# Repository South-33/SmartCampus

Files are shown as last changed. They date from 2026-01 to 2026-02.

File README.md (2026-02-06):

# Smart Classroom System

A two-node wireless system for secure gate access and intelligent energy management.

---

## System Overview

| Node | Role | Components |
|---|---|---|
| **Node A (Gatekeeper)** | Door access control | ESP32 + PN532 NFC + Finger Vein + Relay |
| **Node B (Watchman)** | Occupancy monitoring & power control | ESP32 + HLK-LD2410C Radar + Relay |
| **Communication** | ESP-NOW (direct ESP-to-ESP) | ~50m indoor range |

---

## Tech Stack

| Layer | Technology | Why |
|---|---|-----|
| **Mobile App** | React Native + Expo | Cross-platform, TypeScript, EAS cloud builds |
| **Backend** | Convex | Real-time, TypeScript, scheduled functions |
| **Firmware** | Arduino/PlatformIO | ESP32 HTTP client to Convex |

### Mobile App Libraries

| Feature | Library |
|---|---|
| NFC | `react-native-nfc-manager` |
| Biometrics (FaceID) | `expo-local-authentication` |
| GPS | `expo-location` |
| Push Notifications | `expo-notifications` |

### Expo Go Limits (Testing)

- Face ID is not available in Expo Go (it falls back to passcode)
- NFC is not available in Expo Go (requires a dev client build)
- Android dev build steps: `mobile/ANDROID_DEV_BUILD.md`

### Architecture

```
┌─────────────────────────────────────────┐
│           MOBILE APP                    │
│   React Native + Expo                   │
└────────────────┬────────────────────────┘
                 │ TypeScript
                 ▼
┌─────────────────────────────────────────┐
│            BACKEND                      │
│   Convex (real-time + scheduled jobs)   │
└────────────────┬────────────────────────┘
                 │ HTTP
                 ▼
┌─────────────────────────────────────────┐
│           HARDWARE                      │
│   ESP32 + PN532 (local whitelist)       │
└─────────────────────────────────────────┘
```

## Hardware Inventory

| Component | Qty | Function | Placement |
|---|-----|---|---|
| ESP32 WROOM-32 | 2 | Microcontrollers | Door frame / Ceiling |
| PN532 NFC Module | 2 | Reader/Tag Emulation | Outside door (1 spare) |
| HLK-LD2410C | 1 | mmWave Presence Sensor | Ceiling (facing room) |
| 5V Relay Module | 2 | Lock control / Power switch | Door frame / Electrical box |
| Waveshare Finger Vein | 1 | Biometric authentication | Door frame (beside NFC) |
| HLK-TX510 Face Recognition | 1 | Secondary biometric | Door frame |
| NTAG215 Cards | 10 | Physical student keys | Student possession |

---

## Wiring Diagrams

### Node A: Gatekeeper (Door) - UPDATED (SAFE)

| Component | Pin | ESP32 Pin | Notes |
|---|-----|---|---|
| **PN532 NFC** | VCC | **VIN (5V)** | Has onboard 3.3V regulator |
| | GND | GND | |
| | SDA | GPIO 21 | Direct connect OK (3.3V I2C) |
| | SCL | GPIO 22 | Direct connect OK (3.3V I2C) |
| **Relay #1** | IN | **GPIO 25** | *Safe pin (not GPIO 4)* |
| **Finger Vein** | VCC | **3V3** | Module requires 3.3V |
| | GND | GND | |
| | TX | GPIO 16 | Direct connect OK (3.3V UART) |
| | RX | GPIO 17 | Direct connect OK (3.3V UART) |
| **TX510 Face** | VCC | **5V Rail** | Module Max 500mA (Supply >800mA rec.) |
| | GND | GND | |
| | TX | GPIO 4 | Direct connect OK (3.3V UART1) |
| | RX | GPIO 5 | Direct connect OK (3.3V UART1) |

> **Note on Level Shifters:**
> - **PN532**: NOT required - uses 3.3V I2C logic despite 5V VCC input
> - **Finger Vein**: NOT required - native 3.3V module
> - **TX510**: NOT required - confirmed 3.3V UART domain (Pins 38/39)
> - Add **4.7K pull-up resistors** on I2C lines (SDA/SCL) for reliable PN532 communication

### Node B: Watchman (Ceiling) - UPDATED (SAFE)

| Component | Pin | ESP32 Pin | Notes |
|---|-----|---|---|
| **HLK-LD2410** | VCC | **VIN (5V)** | MUST be 5V. 3.3V will not work. |
| | GND | GND | |
| | TX | GPIO 16 | Direct connect OK |
| | RX | GPIO 17 | Direct connect OK |
| **Relay #2** | IN | **GPIO 26** | *Moved from GPIO 5 (Boot risk)* |

> ⚠️ **Critical:** Node B must be powered by a separate always-on circuit. If Relay #2 controls its own power, opening it kills the ESP32.

---

## User Flows

### Flow 1: Card Onboarding

Student links their physical NFC card to their account (one-time setup).

```mermaid
flowchart TD
    A[🎓 Student receives card] --> B[Opens app]
    B --> C[Taps 'Link Card']
    C --> D[📱 Phone reads card UID]
    D --> E{Success?}
    E -->|Yes| F[Send to server]
    E -->|No| G[❌ Retry]
    F --> H[✅ Card linked!]
```

---

### Flow 2: Physical Card Access

Student taps card. **ALWAYS uses local whitelist (instant, no server call).**

```mermaid
flowchart TD
    A[🎓 Tap card] --> B[PN532 reads UID]
    B --> C[Check LOCAL whitelist]
    C --> D{In list?}
    
    D -->|Yes| E[🔓 Door opens]
    D -->|No| F[❌ Denied]
    
    E --> G[Queue access log]
    G --> H{WiFi?}
    H -->|Yes| I[Sync log now]
    H -->|No| J[Sync later]
```

> 💡 **No server call during tap.** Whitelist is pre-synced from server.

---

### Flow 3: Phone Access (Open Gate Only)

No biometric needed. **ALWAYS uses local whitelist.**

```mermaid
flowchart TD
    A[🎓 Open app] --> B[Tap 'Open Gate']
    B --> C[📱 NFC Writer mode]
    C --> D[60 second timer]
    D --> E[Tap phone to reader]
    E --> F[Phone writes: studentId]
    F --> G[ESP32 checks LOCAL whitelist]
    G --> H{In list?}
    
    H -->|Yes| I[🔓 Door opens]
    H -->|No| J[❌ Denied]
    
    I --> K[Queue log for sync]
```

**Payload:** `{ studentId, action: "OPEN_GATE" }`

**App Screen States:**

```mermaid
flowchart LR
    A[📱 Timer Screen] -->|Phone detects scan| B[✅ Success Screen]
    A -->|60s expires| C[❌ Timeout Screen]
```

| State | UI | Trigger |
|---|-----|---|
| **Timer** | "⏱️ 47 seconds - Tap phone to reader" | User clicks Open Gate |
| **Success** | "✅ Scanned! Door should open" | NFC write callback fires |
| **Timeout** | "❌ Time expired, try again" | 60 seconds pass |

---

### Flow 4: Attendance (Biometric Required)

Opens door AND records attendance. **Requires FaceID/Fingerprint.**

```mermaid
flowchart TD
    A[🎓 Open app] --> B[Tap 'Attendance']
    B --> C{Has biometric HW?}
    
    C -->|No| D[❌ Not supported]
    C -->|Yes| E{Biometric enrolled?}
    
    E -->|No| F[⚠️ Set up in Settings]
    E -->|Yes| G[Prompt FaceID]
    
    G --> H{Auth OK?}
    H -->|No| I[❌ Failed]
    H -->|Yes| J[📱 NFC Writer mode]
    
    J --> K[Capture: studentId + time + GPS]
    K --> L[60 second timer]
    L --> M[Tap phone to reader]
    M --> N[ESP32 stores with scanOrder]
    
    N --> O{WiFi?}
    O -->|Online| P[POST + serverTime]
    O -->|Offline| Q[Queue in NVS]
    
    P --> R[🔓 Door + ✅ Attendance]
    Q --> S[🔓 Door + 📋 Queued]
```

**Payload:** `{ studentId, deviceTime, gps, action: "ATTENDANCE" }`

**ESP32 adds:** `{ scanOrder, espTime, synced: false }`

---

### Flow 5: Energy Saving

Radar cuts power when room is empty for 15 minutes.

```
STATE MACHINE:

┌──────────────────────────────────────────────────────────────┐
│                                                              │
│   ┌─────────┐    No motion     ┌─────────┐    15 min     ┌─────────┐
│   │OCCUPIED │ ───────────────► │  GRACE  │ ────────────► │ STANDBY │
│   │Power ON │                  │Power ON │               │Power OFF│
│   └─────────┘                  └─────────┘               └─────────┘
│        ▲                            │                         │
│        │                            │ Motion                  │ Motion
│        │                            ▼                         ▼
│        └──────────────────── INSTANT RECOVERY ◄───────────────┘
│                                                              │
└──────────────────────────────────────────────────────────────┘
```

| State | Power | Trigger to next state |
|---|---|---|
| **OCCUPIED** | ON | No motion → GRACE |
| **GRACE** | ON | 15 min no motion → STANDBY |
| **STANDBY** | OFF | Motion detected → OCCUPIED |

---

## Offline Mode

System is **local-first**. No server calls during validation. Server only manages whitelist updates.

### Architecture

**Two-way sync between ESP32 and Server:**

| Direction | What | When |
|---|---|---|
| **Server → ESP32** | Whitelist updates | Periodic (every hour) or on boot |
| **ESP32 → Server** | Access logs + attendance | When WiFi available |

```
┌────────────────────────────────────────────────────────────────┐
│                     SERVER (Convex)                            │
│  • Manage students & rooms                                     │
│  • Push whitelist to each ESP32                                │
│  • Receive logs from ESP32                                     │
└───────────────────────────┬────────────────────────────────────┘
                            │
            ┌───────────────┴───────────────┐
            │         WiFi Sync             │
            │  (not during tap, only sync)  │
            └───────────────┬───────────────┘
                            │
┌───────────────────────────┴────────────────────────────────────┐
│                     ESP32 (Local)                              │
│  • Store room whitelist in NVS                                 │
│  • Validate taps LOCALLY (instant)                             │
│  • Queue logs until WiFi available                             │
└────────────────────────────────────────────────────────────────┘
```

**Key point:** Student taps → validated locally → door opens. No WiFi needed.

### What Happens When

| Event | Action |
|---|---|
| **Student taps** | Check LOCAL whitelist → instant response |
| **WiFi available** | Sync queued logs + check for whitelist updates |
| **Admin adds student** | Server updates whitelist → ESP32 pulls on next sync |
| **WiFi down** | Everything still works, logs queue locally |

### Timestamp Handling

| Mode | Source | Label | Accuracy |
|---|---|---|---|
| Online | Server | `timestampServer` | ✅ Accurate |
| Offline | ESP32 | `timestampLocal` | ⚠️ May drift |

**On reconnect:** Calculate offset, correct queued records.

---

### Anti-Cheat Mechanisms

#### 1. Attendance Time Window

**Single scan only** (no scan OUT = no queue at end of class).

Window: **15 min before class** → **mid-class** (50% of class duration)

```
Class: 09:00 - 10:30 (90 min)

            ATTENDANCE WINDOW
        ◄─────────────────────►
        
08:45   09:00              09:45   10:30
  │       │                  │       │
  ├───────┼──────────────────┤       │
  │15 min │     OPEN         │CLOSED │
  │before │   (can scan)     │       │
```

| Attempt Time | Class 09:00-10:30 | Result |
|---|---|---|
| 08:30 | Too early | ❌ Rejected |
| 08:50 | 10 min before | ✅ Valid |
| 09:15 | During class | ✅ Valid |
| 09:45 | Mid-class cutoff | ✅ Valid (last chance) |
| 10:00 | Past mid-class | ❌ Rejected |

#### 2. Phone Internet Check

Phone includes its internet status in the payload:

```json
{
  "studentId": "stu_123",
  "deviceTime": 1706012345,
  "timeSource": "ntp",      // "ntp" = internet time, "local" = device clock
  "hasInternet": true,
  "gps": { "lat": 13.7, "lng": 100.5 },
  "action": "ATTENDANCE"
}
```

| timeSource | Meaning | Trust Level |
|---|---|---|
| `ntp` | Phone fetched time from internet | ✅ High |
| `local` | Phone used device clock | ⚠️ Low |

#### 3. Suspicious Pattern Detection

Flag students who consistently have "no internet":

```typescript
// Server-side check
function checkSuspiciousPatterns(studentId: string, logs: AttendanceLog[]) {
  const recentLogs = logs.filter(l => l.studentId === studentId && isWithinDays(l, 7));
  const noInternetCount = recentLogs.filter(l => l.timeSource === "local").length;
  const totalCount = recentLogs.length;
  
  // If >50% of attendance has no internet in past week → suspicious
  if (noInternetCount / totalCount > 0.5) {
    alertAdmin({
      type: "SUSPICIOUS_PATTERN",
      studentId,
      message: `${noInternetCount}/${totalCount} scans with no internet this week`
    });
  }
}
```

**Red flags to auto-detect:**
| Pattern | Action |
|---|---|
| >50% "no internet" in 7 days | ⚠️ Flag to admin |
| Attendance outside time window | ❌ Reject |
| GPS > 100m from room | ⚠️ Flag to admin |
| deviceTime vs espTime > 5 min | 🚨 Use espTime only |
| **1 deviceId + 2 accounts in 12h** | 🚨 **Account sharing** |

#### 5. Device Binding (Anti-Sharing)

**Problem:** Student A logs into app, scans attendance, logs out, gives phone to Student B, who logs in and scans.

**Solution:** Include `deviceId` in every payload. Server tracks which devices are used by which accounts.

```json
{
  "studentId": "stu_123",
  "deviceId": "E621E1F8-C36C-495A-93FC-0C247A3E6E5F",
  "deviceTime": 1706012345,
  "action": "ATTENDANCE"
}
```

**Server-side check:**
```typescript
function checkDeviceSharing(deviceId: string, studentId: string) {
  const recentScans = getScansInLast12Hours(deviceId);
  const uniqueAccounts = new Set(recentScans.map(s => s.studentId));
  
  if (uniqueAccounts.size > 1) {
    // 🚨 Same device, multiple accounts = sharing
    alertAdmin({
      type: "DEVICE_SHARING",
      deviceId,
      accounts: [...uniqueAccounts],
      message: `Device used by ${uniqueAccounts.size} accounts in 12h`
    });
  }
}
```

| Scenario | Result |
|---|---|
| 1 device, 1 account | ✅ OK |
| 1 device, 2 accounts in 12h | 🚨 Flag both students |
| 1 device, 2 accounts in 7 days | ⚠️ Maybe new phone, allow |

#### 4. Scan Order (Position)

Students can lie about timestamp. They **cannot** lie about position in line.

| scanOrder | studentId | deviceTime | espTime | Status |
|---|---|---|---|---|
| 1 | stu_007 | 09:01:23 | 09:01:25 | ✅ OK |
| 2 | stu_003 | 09:01:45 | 09:01:30 | ✅ OK |
| 3 | stu_012 | **08:55:00** | 09:01:35 | 🚨 SUS |
| 4 | stu_001 | 09:02:10 | 09:01:40 | ✅ OK |

→ Student #3 claims 08:55 but is position 3. **Use espTime as truth.**

**Scan Order Memory (ESP32 NVS):**

| Data per scan | Size |
|---|---|
| `scanOrder` (uint16) | 2 bytes |
| `studentId` (8 chars) | 8 bytes |
| `espTime` (uint32) | 4 bytes |
| `synced` flag | 1 byte |
| **Total per scan** | **~15 bytes** |

| Scenario | Calculation | Result |
|---|---|---|
| 50 scans/day × 15 bytes | 750 bytes/day | Tiny |
| NVS usable space | ~12-16 KB | Huge margin |
| Days before overflow (no sync) | 16,000 ÷ 750 | **~21 days** |

> 💡 With WiFi syncing every hour, you'll never hit NVS limits. If overflow occurs (rare), oldest records are deleted.

**Flow:**
```
Class starts → scanOrder = 0
Student 1 taps → scanOrder = 1, queued
Student 2 taps → scanOrder = 2, queued
...
WiFi available → Batch upload all → Clear queue
Next class → scanOrder = 0 (reset per class session)
```

---

### Local Whitelist

Each ESP32 stores only students allowed in **its room**:

```json
{
  "whitelistVersion": 42,
  "entries": [
    { "cardUID": "04:A3:2B:...", "studentId": "stu_001" },
    { "cardUID": "04:B7:3C:...", "studentId": "stu_007" }
  ]
}
```

**Sync:** `GET /whitelist?room=101&version=42` → 304 or new list.

---

## Access Control Model

### User Roles

| Role | Door Access | Scan IN | Scan OUT | Biometric | Notes |
|---|---|---|---|---|---|
| **Student** | Enrolled rooms only | ✅ Required | ❌ Not required | IN only | GPS geofencing |
| **Teacher** | All rooms | ✅ Required | ✅ Required | Both IN & OUT | Logs teaching hours |
| **Cleaner/Staff** | All rooms | ❌ Optional | ❌ Optional | None | Access logged only |
| **Admin** | All rooms + dashboard | ❌ Optional | ❌ Optional | None | Can manage everything |

> 💡 **Why no student scan-out?** Students rush to leave class simultaneously. Requiring scan-out creates bottlenecks. Use radar occupancy detection instead if class duration data is needed.

> ⚠️ **Biometric Clarification:** We use on-device authentication (FaceID/Fingerprint). The app receives `true/false` — **no biometric data is collected or transmitted**. Only GPS is collected for geofencing.

**How it works:**
- `role: "student"` → Check `allowedRooms` array
- `role: "teacher" | "cleaner" | "admin"` → Skip room check, allow all

### Database Schema

```typescript
// users (students, teachers, cleaners, admins)
{
  _id: "usr_12345",
  name: "John Doe",
  role: "student" | "teacher" | "cleaner" | "admin",
  status: "enrolled" | "graduated" | "expelled",  // Never delete, just archive
  cardUID: "04:A3:2B:1C:7D:00:00",    // 1 account = 1 card (linking new card overwrites old)
  deviceId: "E621E1F8-C36C...",       // Bound phone for anti-sharing
  allowedRooms: ["room_101", "room_102"]  // Only used if role = "student"
}
```

> 💡 **Archiving Policy:** Users are never deleted. When a student graduates or is expelled, set `status` accordingly. Old attendance records remain for historical reference.

> ⚠️ **1:1 Card Binding:** Each account can only have ONE linked NFC card. If a student links a new card, the old `cardUID` is overwritten. This prevents students from having multiple cards.

```typescript
// rooms
{
  _id: "room_101",
  name: "Computer Lab 101",
  nodeId: "esp32_node_a_001",
  gps: { lat: 13.7563, lng: 100.5018 }
}

// accessLogs
{
  studentId: "stu_12345",
  roomId: "room_101",
  method: "card" | "phone",
  action: "OPEN_GATE" | "ATTENDANCE",
  result: "granted" | "denied",
  timestamp: "2026-01-22T10:30:00Z",
  timestampType: "server" | "local",
  scanOrder?: 5,
  gps?: { lat, lng }
}
```

---

## Security Strategy

| Layer | Implementation |
|---|---|
| **Something you have** | NFC Card / iPhone |
| **Something you are** | FaceID (attendance only) |
| **Somewhere you are** | GPS verification |
| **Replay protection** | scanOrder + nonce |
| **Offline security** | Local whitelist, no signing keys |

### Threat Mitigations

| Threat | Mitigation |
|---|---|
| Fake studentId | Check whitelist |
| Fake timestamp | Use scanOrder + espTime |
| Fake GPS | Flag if > 100m from room |
| Replay attack | lastScan[studentId] < 30 min |
| Stolen ESP32 | No secrets stored |
| Power loss | NVS (flash), not RAM |
| Photo/Video Spoofing | TX510 3D + IR Live Detection |

---

## Software Components

### Firmware (ESP32)
- [x] Finger Vein library (enroll, verify, delete users)
- [ ] NFC read/write handling
- [ ] Local whitelist validation
- [ ] Attendance queue (NVS)
- [ ] WiFi check + sync
- [ ] OTA updates
- [ ] NTP time sync

### Backend (Convex)
- [ ] Student/room management
- [ ] Whitelist endpoint
- [ ] Attendance validation
- [ ] Access logs

### Mobile App (iOS)
- [ ] NFC Writer mode (Core NFC)
- [ ] FaceID (LocalAuthentication)
- [ ] GPS capture
- [ ] Demo mode for App Store
- [ ] Push notifications (see below)

### Push Notifications

Server sends push notifications based on class schedule:

| Trigger | Time | Message |
|---|---|---|
| **Window opens** | 15 min before class | "📚 CS101 attendance is now open" |
| **Class starts** | Exact start time | "⏰ CS101 has started - scan now!" |
| **Reminder** | 15 min after start | "⚠️ You haven't checked in for CS101" |
| **Last chance** | Mid-class (cutoff) | "🚨 Last chance to scan for CS101!" |
| **Missed** | After cutoff | "❌ You missed CS101 attendance" |

```mermaid
flowchart TD
    A[Class 09:00-10:30] --> B[08:45: 'Attendance open']
    B --> C{Attended?}
    C -->|Yes| D[No more reminders]
    C -->|No| E[09:00: 'Class started']
    E --> F{Attended?}
    F -->|Yes| D
    F -->|No| G[09:15: 'Not checked in']
    G --> H{Attended?}
    H -->|Yes| D
    H -->|No| I[09:45: 'Last chance!']
    I --> J{Attended?}
    J -->|Yes| D
    J -->|No| K[09:46: 'Missed attendance']
```

**Implementation:** Use scheduled push via Convex + Expo Push Notifications (or APNs).

---

## System Management

### Device Registration (Chip ID)

Each ESP32 has a unique hardware ID. Use this for automatic registration:

```
ESP32 first boot:
   │
   ├─► POST /register { chipId: "A1B2C3D4E5F6" }
   │
   ▼
Server creates: { chipId: "A1B2C3D4E5F6", roomId: null, name: "Unassigned" }
   │
   ▼
Admin dashboard: "New device! Assign to Room 305"
   │
   ▼
Server updates: { chipId: "A1B2C3D4E5F6", roomId: "room_305" }
```

**Database schema:**
```typescript
// devices
{
  chipId: "A1B2C3D4E5F6",      // Permanent hardware ID
  roomId: "room_305",          // Assigned from admin panel
  name: "Room 305 Door",       // Human-readable
  firmwareVersion: "1.2.3",
  lastSeen: "2026-01-23T12:00:00Z",
  status: "online"
}
```

> ✅ Same firmware for all devices. Room assignment done in admin panel.

---

### WiFi Credential Management

Server stores WiFi credentials. ESP32 pulls on boot:

```typescript
// wifiCredentials (single row)
{
  primary:   { ssid: "SchoolWiFi", pass: "current123" },
  secondary: { ssid: "SchoolWiFi", pass: "newpass456" }
}
```

**ESP32 connection logic:**
1. Try `primary` → Connected? ✅ Done
2. Failed? Try `secondary` → Connected? ✅ Report to server
3. Both failed? Enter AP mode for manual config

**Admin workflow to change WiFi password:**
1. Add new password as `secondary` in dashboard
2. Wait 1 hour (all ESP32s pull new creds)
3. Change actual WiFi password on router
4. ESP32s reconnect using `secondary`
5. Promote `secondary` → `primary`

> ✅ Zero downtime WiFi password changes.

---

### OTA Firmware Updates

ESP32 pulls firmware updates on boot:

| Component | Method | Downtime |
|---|---|---|
| ESP32 Firmware | HTTP OTA | ~30 sec reboot |
| Mobile App (JS) | Expo Updates | 0 (instant) |
| Backend | `npx convex deploy` | 0 |

**Staged rollout for safety:**
```typescript
// firmwareVersions
{
  version: "1.2.3",
  rolloutPercentage: 10,  // Start with 10%
  url: "https://storage/.../v1.2.3.bin"
}
```

- Day 1: 10% of devices update → Watch for errors
- Day 2: 50% of devices update → Still OK?
- Day 3: 100% of devices update

> ⚠️ If bug found, set `rolloutPercentage: 0` to pause immediately.

---

### Heartbeat Monitoring

ESP32 sends heartbeat every 5 minutes:

```typescript
POST /heartbeat {
  chipId: "A1B2C3D4E5F6",
  uptime: 12345,
  freeMemory: 45000,
  firmwareVersion: "1.2.3"
}
```

**Scheduled job (every 10 min):**
- Find devices where `lastSeen > 15 min ago`
- Alert admin: "Room 305 is offline!"

---

### Power Failure Recovery

Everything survives power loss:

| Data | Storage | Survives Reboot? |
|---|---|---|
| Whitelist | NVS (flash) | ✅ Yes |
| Queued attendance | NVS (flash) | ✅ Yes |
| Clock | NTP sync on boot | ✅ Yes |

**On boot:**
1. Connect WiFi (try primary, then secondary)
2. Sync NTP time
3. Check for firmware updates
4. Pull latest whitelist
5. Sync any queued logs
6. Resume normal operation

---

## Admin Dashboard

### Core Features

| Feature | Description |
|---|---|
| **Device Management** | View all ESP32s, assign to rooms, see online/offline status |
| **User Management** | Add/edit students, teachers, cleaners. Assign rooms. |
| **Attendance Logs** | View, filter, export attendance data |
| **Suspicious Activity** | View flagged students (GPS mismatch, device sharing, etc.) |
| **Firmware Updates** | Upload new firmware, control rollout % |
| **Audit Log** | Who did what when (all admin actions logged) |

### Emergency Override

Admin can bypass the system when needed:

| Override | Effect |
|---|---|
| **Unlock Room X** | Opens door immediately (logged) |
| **Disable Room X** | Door stays unlocked, attendance disabled |
| **Lock All** | Emergency lockdown (all doors locked) |

> ⚠️ All overrides are logged with admin ID and timestamp.

### Room Control Panel

Admin can view and control every component in each room:

**Real-time Status (per room):**
```
┌─────────────────────────────────────────────────────────────┐
│ Room 305 - Computer Lab                                     │
├─────────────────────────────────────────────────────────────┤
│                                                             │
│  🔌 ESP32 (Door)      ● Online    v1.2.3    ↻ 2 min ago    │
│  🔌 ESP32 (Radar)     ● Online    v1.2.3    ↻ 2 min ago    │
│  📡 Radar Sensor      ● Detecting motion                    │
│  🔒 Door Lock         ● Locked                              │
│  💡 Power Relay       ● ON                                  │
│  👥 Occupancy         ● 12 people (estimated)               │
│                                                             │
├─────────────────────────────────────────────────────────────┤
│  [🔓 Unlock]  [💡 Lights ON]  [💡 Lights OFF]  [⚠️ Override] │
└─────────────────────────────────────────────────────────────┘
```

**Manual Controls:**
| Control | Effect |
|---|---|
| **Unlock Door** | Opens door for 10 seconds |
| **Lights ON** | Force power relay ON |
| **Lights OFF** | Force power relay OFF (overrides radar) |
| **Reset Radar** | Restart motion detection |
| **Reboot ESP32** | Remote restart device |

---

## Data Retention

| Data Type | Retention | Reason |
|---|---|---|
| Attendance logs | **4 years** | Academic records |
| Access logs (door) | 1 year | Security |
| Device heartbeats | 30 days | Debugging |
| Audit logs | 4 years | Accountability |

**Backup:** Monthly export to CSV/Excel stored offline.

---

## User Onboarding

### New Student Flow

```
1. Admin creates account in dashboard
   │
   ▼
2. Student receives login credentials (email/SMS)
   │
   ▼
3. Student downloads app, logs in
   │
   ▼
4. Student taps "Link Card" → Scans NFC card
   │
   ▼
5. Card linked to account ✅ Ready to use
```

### Lost Card

```
1. Student reports to admin
   │
   ▼
2. Admin gives new card
   │
   ▼
3. Student scans new card in app
   │
   ▼
4. Old card automatically unlinked (1:1 binding)
```

---

## Deployment Strategy

| Phase | Scope | Goal |
|---|---|---|
| **Phase 1** | Personal testing | Validate hardware works |
| **Phase 2** | 1 classroom | End-to-end testing with real users |
| **Phase 3** | 1 building/floor | Scale testing, iron out issues |
| **Phase 4** | Campus-wide | Full deployment |

> Start small. Fix issues. Expand gradually.

---

## Development Phases

### Phase 1: Hardware ✅
- [x] Order components

### Phase 2: Validation
- [ ] ESP32 + PN532 (I2C)
- [ ] ESP32 + HLK-LD2410C (UART)
- [x] ESP32 + Waveshare Finger Vein (UART) - Library created: `firmware/lib/FingerVein/`
- [ ] ESP-NOW between nodes
- [ ] Relay actuation

### Phase 3: Core Logic
- [ ] 15-min timer
- [ ] NFC token read/write
- [ ] Convex backend

### Phase 4: Integration
- [ ] Node A ↔ Server ↔ Node B
- [ ] iOS app with FaceID + NFC
- [ ] End-to-end testing

### Phase 5: Deployment
- [ ] Install in classroom
- [ ] Wire to door lock
- [ ] Production deployment

---

## Bill of Materials

| Item | Price |
|---|---|
| ESP32 WROOM-32 (2pcs) | $9.29 |
| PN532 NFC Module (2pcs) | $8.37 |
| HLK-LD2410C Radar | $2.52 |
| 5V Relay Module (2pcs) | $1.32 |
| NTAG215 Cards (10pcs) | $6.48 |
| Dupont Wires F-F (20pin) | $4.16 |
| USB-C Cables (2) | $5.33 |
| Soldering Iron 80W | $12.91 |
| **Order 1 Subtotal** | **$55.51** |
| | |
| Waveshare Finger Vein | $29.14 |
| HLK-TX510 Face Recognition | $42.71 |
| Dupont Wires M-M (20pin) | $4.26 |
| Dupont Wires F-F (20pin) | $4.16 |
| Logic Level Converters (10pcs) | $1.94 |
| 4.7K Resistors (100pcs) | $0.80 |
| USB-C Breakout (5pcs) | $4.32 |
| Waterproof Box IP65 | $12.25 |
| Cable Glands PG7 (10pcs) | $4.79 |
| Protoboard 7x9cm (3pcs) | $2.91 |
| Protoboard 5x7cm (3pcs) | $2.10 |
| Heat Shrink Kit (164pcs) | $1.78 |
| MB-102 Breadboard Kit | $5.44 |
| ANENG SZ308 Multimeter | $6.80 |
| **Order 2 Subtotal** | **~$123** |
| | |
| **GRAND TOTAL** | **~$178** |

---

## Cost Projections (~100 students)

| Service | Free Tier | Expected Usage | Monthly Cost |
|---|---|---|---|
| **Convex** | 1M function calls | ~50k calls | **$0** |
| **Expo Push** | Unlimited | ~10k/month | **$0** |
| **EAS Build** | 15 builds/month | 2-3 builds | **$0** |
| **Total** | | | **$0/month** |

> 💡 Free tier covers up to ~500-1000 active users. After that, Convex is ~$25/month.

---

## Admin Notifications

Server pushes alerts to admins for critical events:

| Event | Alert | Priority |
|---|---|---|
| **Device offline** | "Room 305 door is offline (15 min)" | 🔴 High |
| **Suspicious activity** | "Student X flagged: 3 GPS mismatches this week" | 🟠 Medium |
| **Device sharing** | "Device used by 2 accounts in 12h" | 🔴 High |
| **Sensor malfunction** | "Room 201 radar not reporting" | 🟠 Medium |
| **Firmware update failed** | "ESP32 A1B2C3 update stuck" | 🟡 Low |

**Teacher notifications:**
| Event | Alert |
|---|---|
| **Class starting** | "CS101 starting in 5 min, 8/30 students checked in" |
| **Low attendance** | "Only 12/30 students checked in for CS101" |

---

## Accessibility

| Feature | Implementation |
|---|---|
| **Haptic feedback** | Vibration on successful scan |
| **VoiceOver support** | All buttons properly labeled |
| **High contrast** | Dark mode with clear status indicators |
| **Large touch targets** | Minimum 44pt tap areas |

---

## Localization (i18n)

| Language | Code | Status |
|---|---|---|
| **English** | `en` | Primary |
| **Khmer** | `km` | Secondary |

> 💡 Use `react-i18next` or Expo's `expo-localization` for language detection.

---

## Hardware Safety

### Magnetic Door Lock (Fail-Safe)

| Power State | Lock State | Reason |
|---|---|---|
| **Power ON** | 🔒 Locked | Normal operation |
| **Power OFF** | 🔓 Unlocked | Fire safety compliance |

> ⚠️ **Fail-safe design:** Magnetic locks require power to stay locked. On power outage, doors automatically unlock. This is intentional for fire safety — no UPS needed.

---

## Edge Cases

### Substitute Teacher

**Flow (designed for non-tech admins):**
```
1. Admin opens dashboard → "Add User"
2. Enters: Name, Phone, Role: "Teacher", Status: "Temporary"
3. System sends SMS/Email with login link
4. Sub logs in → Can access all rooms for today
5. End of day → Admin sets Status: "Inactive" (or auto-expires)
```

> 💡 **Keep it simple:** Same flow as adding any teacher, just mark as "Temporary". No special code needed.

### Manual Attendance Override

**When:** Student arrives late with valid excuse (doctor's note, etc.)

**Teacher Flow:**
```
1. Teacher opens app → "My Classes" → "CS101"
2. Views attendance roster for today
3. Taps absent student → "Mark Present (Manual)"
4. Enters reason: "Doctor's note"
5. Server logs: { method: "manual", addedBy: "teacher_123", note: "Doctor's note" }
```

> 💡 Teachers can only edit attendance for their own classes. Admins can edit any class.

### Data Migration

**Phase 1 (Now):** Manual data entry for demo/pilot
**Phase 2 (Later):** Import from existing MySQL system

```
Existing System (MySQL) → Export CSV → Convex Import Script → Our System
```

> ⚠️ **Deferred:** Data shape unknown. Focus on getting system working first, then work with school IT for migration.

---

## Demo Mode (App Store)

> ⚠️ **REMINDER:** iOS App Store requires apps to be testable without real hardware.

**Implementation:**
- Add "Demo Mode" toggle in Settings (hidden, triple-tap logo to reveal)
- Mock NFC scans with fake success responses
- Skip biometric check (return `true`)
- Show fake "Door Opened!" confirmation

**For App Store Review:**
- Include demo credentials in App Store notes
- Reviewer can test full flow without ESP32 hardware

---

## In-App Issue Reporting

### Automatic Prompt

When user is waiting to scan (NFC writer mode active):

```
0-15 sec:  [Timer Screen] "⏱️ 45 seconds - Tap phone to reader"
           └── Small "Having trouble?" link at bottom

15-30 sec: [Timer Screen] "⏱️ 30 seconds - Tap phone to reader"
           └── Button EXPANDS: "🆘 Having trouble? Tap here"

After tap: [Issue Report Screen]
           • What's wrong?
             ○ Door not responding
             ○ NFC not detecting my phone
             ○ Reader seems broken
             ○ Other: [text field]
           • [Submit Report]
```

### What Happens

```
User submits report
  └→ Push notification to admin: "🚨 Room 305: NFC issue reported by John Doe"
  └→ Logged in dashboard with timestamp, user, room, issue type
  └→ User sees: "✅ Admin notified. Try the next door or wait for help."
```

---

## Remote Debugging

### ESP32 Log Upload

ESP32 sends debug logs to Convex for remote troubleshooting:

```typescript
// deviceLogs (Convex table)
{
  chipId: "A1B2C3D4E5F6",
  timestamp: "2026-01-23T12:00:00Z",
  level: "error" | "warn" | "info" | "debug",
  message: "NFC read timeout after 5000ms",
  metadata: { attempts: 3, lastUID: null }
}
```

**What gets logged:**

| Event | Level | Example |
|---|---|---|
| NFC read success | `info` | "Card read: 04:A3:2B:..." |
| NFC read timeout | `warn` | "NFC timeout after 5s" |
| WiFi disconnect | `warn` | "WiFi lost, queuing logs" |
| Relay actuation | `info` | "Door unlocked for 5s" |
| Boot/restart | `info` | "Boot: v1.2.3, free mem: 45KB" |
| Crash/exception | `error` | "Stack overflow in task X" |

**Retention:** 7 days (auto-delete old logs to save space)

**Admin Dashboard:** Filter logs by device, level, time range. Search for errors.

> 💡 **Remote fix:** If you see "NFC timeout" errors spiking, you know something's wrong without being on-site.

---

## Resources

- [ESP-NOW Docs](https://docs.espressif.com/projects/esp-idf/en/latest/esp32/api-reference/network/esp_now.html)
- [PN532 Library](https://github.com/adafruit/Adafruit-PN532)
- [HLK-LD2410 Library](https://github.com/ncmreynolds/ld2410)
- [Convex Docs](https://docs.convex.dev/)
- [Waveshare Finger Vein Wiki](https://www.waveshare.com/wiki/Finger_Vein_Scanner_Module_(A))
- [Finger Vein Protocol Manual (PDF)](https://files.waveshare.com/wiki/Finger_Vein_Scanner_Module_B/Finger_Vein_Module_Communication_Protocol_EN.pdf)
- [Finger Vein Python Demo](https://github.com/waveshareteam/Finger_Vein_Demo_Code)

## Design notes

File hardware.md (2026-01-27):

# Hardware Inventory & Resource Tracker

> Last Updated: January 2026
> Status: **ALL ORDERED - AWAITING DELIVERY**

---

## Quick Status Dashboard

```
+============================================================================+
|                        SYSTEM RESOURCE OVERVIEW                            |
+============================================================================+

  CONTROLLERS & SENSORS
  ---------------------
  ESP32 Nodes        [##########] 2/2 FULL      No spare controllers
  NFC Modules        [#####-----] 1/2 USED      1 spare for 2nd door
  Radar Sensors      [##########] 1/1 FULL      Buy more for expansion
  Finger Vein        [##########] 1/1 ORDERED   Awaiting delivery
  Face Recognition   [##########] 1/1 ORDERED   Awaiting delivery

  ACTUATORS & POWER
  -----------------
  Relay Modules      [##########] 2/2 FULL      Buy more for expansion
  USB-C Cables       [##########] 2/2 FULL      For flashing
  USB-C Breakouts    [#---------] 1/5 ORDERED   4 spare after Node A
  Level Shifters     [----------] 0/10 ORDERED  All 10 spare (Node A 3.3V confirmed)

  WIRING & PROTOTYPING
  --------------------
  Dupont F-F 30cm    [#######---] 28/40 USED    ~12 spare wires
  Dupont M-M 30cm    [####------] 6/20 USED     ~14 spare wires
  Breadboard Wires   [----------] 0/65 USED     All 65 for testing
  Protoboards        [#---------] 1/6 USED      5 spare boards
  NFC Cards          [----------] 0/10 USED     All 10 for students

+============================================================================+
```

---

## Order Status Overview

| Category | Status | Est. Total |
|---|---|---|
| **Order 1** | ORDERED | $55.51 |
| **Order 2** | ORDERED | ~$123 |
| **GRAND TOTAL** | | **~$178** |

---

## Part 1: Already Ordered (AliExpress - $55.51)

These items are ordered and cannot be changed.

| # | Item | Qty | Price | Store | Notes |
|---|---|-----|---|---|---|
| 1 | **ESP32 WROOM-32D** (CH340C, TYPE-C) | 2 | $9.29 | A+ Dropship | Main controllers |
| 2 | **PN532 NFC RFID Module V3** (2pcs set) | 2 | $8.37 | EGBO Store | I2C/SPI/HSU modes |
| 3 | **HLK-LD2410C Radar Sensor** | 1 | $2.52 | Shenzhen Hi-Link | mmWave presence |
| 4 | **5V Relay Module** (1-channel, 2pcs) | 2 | $1.32 | TZT 123 Official | Door lock + lights |
| 5 | **NTAG215 NFC Cards** (10pcs black) | 10 | $6.48 | nerina Store | Student ID cards |
| 6 | **Dupont Wire F-to-F** (30cm, 20pin) | 20 | $4.16 | Shop1103734083 | Sensor connections |
| 7 | **USB-C Cable 3A** (1m, black, 2pcs) | 2 | $5.33 | Ugreen Official | Flashing/power |
| 8 | **Soldering Iron 80W** (220V EU plug) | 1 | $12.91 | Firsour Tools | Adjustable temp |

**Order 1 Total:** $55.51 (incl. shipping/discounts)

---

## Part 2: Ordered - Awaiting Delivery (~$123)

These items have been ordered and are currently in transit.

### Core Components

| # | Item | Qty | Price | Store | Purpose |
|---|---|-----|---|---|---|
| 1 | **Waveshare Finger Vein Module (A)** | 1 | $29.14 | Ditu Technology | Primary biometric |
| 2 | **HLK-TX510 Face Recognition Test Suit** | 1 | $42.71 | HI-LINK Component | Secondary biometric (cables included) |

### Wiring & Connections

| # | Item | Qty | Price | Store | Purpose |
|---|---|-----|---|---|---|
| 3 | **Dupont Wire M-to-M** (30cm, 20pin) | 20 | $4.26 | Shop1103734083 | Protoboard soldering |
| 4 | **Dupont Wire F-to-F** (30cm, 20pin) | 20 | $4.16 | Shop1103734083 | Sensor connections |
| 5 | **Logic Level Converter 4-ch** (10pcs) | 10 | $1.94 | Si Tai&SH IC | 3.3V <-> 5V safety |
| 6 | **4.7K Resistors** (100pcs) | 100 | $0.80 | Shop911191007 | I2C pull-ups |

### Power & Mounting

| # | Item | Qty | Price | Store | Purpose |
|---|---|-----|---|---|---|
| 7 | **USB-C Breakout Board** (5pcs) | 5 | $4.32 | Practical Tool 47 | Power rail injection |
| 8 | **Waterproof Box IP65** (158x90x60mm, clear) | 1 | $12.25 | AIRLGEE Electrical | Outdoor enclosure |
| 9 | **Cable Glands PG7** (10pcs) | 10 | $4.79 | Home Improvement | Weatherproof cable entry |
| 10 | **Protoboard 7x9cm** (double-sided) | 3 | $2.91 | TZT 123 Official | Main circuit board |
| 11 | **Protoboard 5x7cm** (double-sided) | 3 | $2.10 | TZT 123 Official | Testing/spare |
| 12 | **Heat Shrink Tubing Kit** (164pcs) | 1 | $1.78 | Ammax Franchise | Wire insulation |

### Testing Equipment

| # | Item | Qty | Price | Store | Purpose |
|---|---|-----|---|---|---|
| 13 | **MB-102 Breadboard Kit** (830pt + power module + 65 wires + case) | 1 | $5.44 | DIYUSER | Test before soldering |
| 14 | **ANENG SZ308 Digital Multimeter** (with probes + box) | 1 | $6.80 | ANENG Official | Voltage/continuity testing |

**Cart Total:** ~$123

---

## Part 4: Component Allocation Map

### Node Assignment Diagram

```
+---------------------------+          +---------------------------+
|     NODE A (Door)         |          |     NODE B (Ceiling)      |
|       "Gatekeeper"        |          |       "Watchman"          |
+---------------------------+          +---------------------------+
|                           |          |                           |
|  [x] ESP32 #1             |  ESP-NOW |  [x] ESP32 #2             |
|  [x] PN532 NFC #1 (I2C)   | <------> |  [x] HLK-LD2410C Radar    |
|  [x] Finger Vein (UART2)  |          |  [x] Relay #2             |
|  [x] TX510 Face (UART1)   |          |  [x] USB-C Cable #2       |
|  [x] Relay #1             |          |                           |
|  [x] USB-C Cable #1       |          |                           |
|  [x] USB-C Breakout #1    |          |                           |
|                           |          |                           |
|  [ ] PN532 NFC #2 (SPARE) |          |                           |
|                           |          |                           |
+---------------------------+          +---------------------------+
         |                                      |
         v                                      v
   +----------+                          +-------------+
   | Door Lock|                          | Lights/AC   |
   +----------+                          +-------------+
```

### Allocation Table

| Component | Qty Owned | Node A | Node B | SPARE | Status |
|---|:---:|:---:|:---:|:-----:|---|
| ESP32 WROOM-32D | 2 | 1 | 1 | 0 | FULL |
| PN532 NFC Module | 2 | 1 | 0 | 1 | 1 spare |
| HLK-LD2410C Radar | 1 | 0 | 1 | 0 | FULL |
| Finger Vein Module | 1 | 1 | 0 | 0 | FULL |
| TX510 Face Recognition | 1 | 1 | 0 | 0 | FULL |
| 5V Relay Module | 2 | 1 | 1 | 0 | FULL |
| Level Shifter 4-ch | 10 | 2 | 0 | 8 | Plenty spare |
| USB-C Breakout | 5 | 1 | 0 | 4 | Plenty spare |
| Protoboard 7x9cm | 3 | 1 | 0 | 2 | Spare |
| Protoboard 5x7cm | 3 | 0 | 0 | 3 | All spare |

---

## Part 5: GPIO & Interface Resource Tracking

### ESP32 #1 (Node A - Door) GPIO Map

```
                    ESP32 #1 PINOUT
     +------------------------------------------+
     |                                          |
     |  3V3 [POWER]-----> Level Shifter LV      | USED
     |  GND [POWER]-----> Common Ground Bus     | USED
     |  VIN [5V]--------> 5V Power Rail         | USED
     |                                          |
     |  GPIO 21 [I2C SDA]---> PN532 SDA         | USED (NFC)
     |  GPIO 22 [I2C SCL]---> PN532 SCL         | USED (NFC)
     |                                          |
      |  GPIO 16 [UART2 RX]<--- Finger Vein TX   | USED (Biometric)
      |  GPIO 17 [UART2 TX]---> Finger Vein RX   | USED (Biometric)
     |                                          |
     |  GPIO 25 [DIGITAL]----> Relay #1 IN      | USED (door lock)
     |                                          |
     |  GPIO 4  [DIGITAL]<---- TX510 TX (Direct Connect)| USED (Face) - ESP RX
     |  GPIO 5  [DIGITAL]----> TX510 RX (Direct Connect)| USED (Face) - ESP TX
     |                                          |
     |  GPIO 18 [DIGITAL]----> (available)      | FREE
     |  GPIO 19 [DIGITAL]----> (available)      | FREE
     |  GPIO 23 [DIGITAL]----> (available)      | FREE
     |  GPIO 26 [DIGITAL]----> (available)      | FREE
     |  GPIO 27 [DIGITAL]----> (available)      | FREE
     |  GPIO 32 [ADC]---------> (available)     | FREE
     |  GPIO 33 [ADC]---------> (available)     | FREE
     |                                          |
     +------------------------------------------+
```

#### ESP32 #1 Resource Summary

| Interface | Status | Current Use | Available |
|---|---|---|---|
| I2C (21/22) | **USED** | PN532 NFC | Can add more I2C devices |
| UART2 (16/17) | **USED** | Finger Vein | - |
| UART1 (4/5) | **USED** | TX510 (Direct Connect) | - |
| GPIO 25 | **USED** | Relay #1 | - |
| GPIO 18,19,23,26,27,32,33 | **FREE** | - | 7 GPIOs available |

### ESP32 #2 (Node B - Ceiling) GPIO Map

```
                    ESP32 #2 PINOUT
     +------------------------------------------+
     |                                          |
     |  3V3 [POWER]-----> (available)           |
     |  GND [POWER]-----> Common Ground Bus     | USED
     |  VIN [5V]--------> Radar VCC, Relay VCC  | USED
     |                                          |
     |  GPIO 21 [I2C SDA]---> (available)       | FREE
     |  GPIO 22 [I2C SCL]---> (available)       | FREE
     |                                          |
      |  GPIO 16 [UART2 RX]<--- Radar TX         | USED (Radar)
      |  GPIO 17 [UART2 TX]---> Radar RX         | USED (Radar)
     |                                          |
     |  GPIO 26 [DIGITAL]----> Relay #2 IN      | USED (lights)
     |                                          |
     |  GPIO 4  [DIGITAL]----> (available)      | FREE
     |  GPIO 5  [DIGITAL]----> (available)      | FREE
     |  GPIO 18 [DIGITAL]----> (available)      | FREE
     |  GPIO 19 [DIGITAL]----> (available)      | FREE
     |  GPIO 23 [DIGITAL]----> (available)      | FREE
     |  GPIO 25 [DIGITAL]----> (available)      | FREE
     |  GPIO 27 [DIGITAL]----> (available)      | FREE
     |  GPIO 32 [ADC]---------> (available)     | FREE
     |  GPIO 33 [ADC]---------> (available)     | FREE
     |                                          |
     +------------------------------------------+
```

#### ESP32 #2 Resource Summary

| Interface | Status | Current Use | Available |
|---|---|---|---|
| I2C (21/22) | **FREE** | - | Can add I2C sensors |
| UART2 (16/17) | **USED** | Radar | - |
| GPIO 26 | **USED** | Relay #2 | - |
| GPIO 4,5,18,19,23,25,27,32,33 + I2C | **FREE** | - | 11 GPIOs available |

---

## Part 6: Wire Budget & Connections

### Total Wire Inventory

| Type | Ordered | In Cart | Kit | Total | For |
|---|:---:|:---:|:---:|:-----:|-----|
| F-to-F 30cm | 20 | 20 | - | **40** | Sensor connections |
| M-to-M 30cm | - | 20 | - | **20** | Protoboard work |
| Breadboard jumpers | - | - | 65 | **65** | Testing on breadboard |
| **GRAND TOTAL** | | | | **125 wires** | |

### Wire Usage Breakdown

```
NODE A WIRING (Door)
====================

ESP32 #1          PN532 NFC           Relay #1        Finger Vein
---------         ---------           --------        -----------
VIN (5V) -------> VCC                 VCC <---+       VCC <-- 3.3V
                                              |
GND ----------+-> GND                 GND <---+------ GND
              |                               |
GPIO 21 ------+-> SDA (+ 4.7K pull-up)        |
GPIO 22 ------+-> SCL (+ 4.7K pull-up)        |
                                              |
GPIO 25 ----------------------------------------> IN
                                              
GPIO 16 <---------------------------------------- TX
GPIO 17 ----------------------------------------> RX

               TX510 Face (3.3V Logic)
               ------------------------------
               VCC <-- 5V Rail (from USB-C Breakout)
               GND <-- Common Ground
               
GPIO 4 <---------------------------------------- TX
GPIO 5 ----------------------------------------> RX

NODE B WIRING (Ceiling)
=======================

ESP32 #2          Radar               Relay #2
---------         ---------           --------
VIN (5V) -------> VCC                 VCC <---+
                                              |
GND ----------+-> GND                 GND <---+-- Common Ground
              |                               |
GPIO 16 <-----+-- TX (Radar TX to ESP RX)     |
GPIO 17 ------+-> RX (ESP TX to Radar RX)     |
                                              |
GPIO 26 ----------------------------------------> IN
```

### Wire Count Per Node

| Node | Component | Wires | Type |
|---|---|:-----:|---|
| A | PN532 NFC | 4 | F-F (VCC, GND, SDA, SCL) |
| A | Finger Vein | 4 | F-F (VCC, GND, TX, RX) |
| A | TX510 Face | 4 | F-F (VCC, GND, TX, RX) |
| A | Level Shifter | 6 | F-F (HV, LV, GND x2, signals x2) |
| A | Relay #1 | 3 | F-F (VCC, GND, IN) |
| A | USB-C Breakout | 4 | M-M (solder to protoboard) |
| A | Pull-up resistors | 2 | Resistor leads |
| **Node A Total** | | **~27** | |
| B | Radar | 4 | F-F (VCC, GND, TX, RX) |
| B | Relay #2 | 3 | F-F (VCC, GND, IN) |
| **Node B Total** | | **~7** | |
| **TOTAL USED** | | **~34** | |

### Wire Budget Summary

```
WIRE BUDGET
===========

F-to-F 30cm:     40 total - 28 used = 12 SPARE
M-to-M 30cm:     20 total - 6 used  = 14 SPARE
Breadboard:      65 total - 0 used  = 65 SPARE (for testing)

VERDICT: Sufficient wires for the project.
```

---

## Part 7: Technical Specifications

### Verified Specifications (HIGH CONFIDENCE)

| Component | Voltage | Logic Level | Level Shifter? | Baud Rate | Source |
|---|---|---|---|---|---|
| **Finger Vein (A)** | 3.3V | 3.3V UART | NO | 57600 | Waveshare Wiki |
| **PN532 NFC V3** | 3.3-5V VCC | 3.3V I2C | NO | - | Adafruit docs |
| **HLK-LD2410C** | 5V | 3.3V UART | NO | 256000 | HiLink docs |
| **HLK-TX510** | 5V | 3.3V UART1 | NO | 115200 | HLK Pin Defs PDF |
| **5V Relay** | 5V | ⚠️ VERIFY | NO | - | Check trigger mode on arrival |

> **⚠️ IMPORTANT NOTE ON TX510 PORTS:**
> - The module has two main UARTs: **USI1** (Pins 36/37) and **UART1** (Pins 38/39).
> - **USI1** is connected to the USB-C port on the manufacturer test kit (via CH340).
> - **UART1** is the separate header we are using for the ESP32 (Pins 38/39).
> - If `UART1` is silent, the module might be configured to output only to `USI1`. Check manufacturer software settings.

> **⚠️ VERIFY ON ARRIVAL:**
> - **Relay Trigger Mode:** May be low-level trigger (pull IN to GND to activate = inverted logic). Check for H/L jumper on board. Test before coding.

### I2C Address Map

| Address | Device | Node | Notes |
|---|---|---|---|
| 0x24 or 0x48 | PN532 NFC | A | Check jumpers on board |
| (free) | - | B | Available for expansion |

---

## Part 8: Power Architecture

### Power Distribution (Node A)

```
[ Power Bank / USB Adapter ]
       |
       | (USB-C Cable)
       v
[ USB-C Breakout Board ] (Soldered to Protoboard)
       |      |
       | VCC  | GND
       v      v
    [ 5V RAIL ] [ GND RAIL ]  <-- The Main Power Bus
        |            |
        +---> ESP32 VIN
        +---> TX510 (5V, ≥ 800mA peak)
        +---> PN532 VCC (5V input, 3.3V internal)
        +---> Relay VCC (5V)
        |
        +---> Level Shifter HV side (UNUSED)
        
    [ 3V3 from ESP32 ]
        |
        +---> Level Shifter LV side (UNUSED)
        +---> Finger Vein VCC (3.3V)
```

### Why USB-C Breakout?

The ESP32's onboard voltage regulator can only supply ~500mA safely. The TX510 requires **≥ 800mA** during face recognition. Connecting high-power devices directly to ESP32 VIN risks:
- Overheating the ESP32's regulator
- Brownouts during peak current
- Unstable operation

The USB-C breakout provides clean 5V directly from the power source, bypassing the ESP32's limitations.

### 🔴 CRITICAL: USB-C Breakout Requires CC Resistors!

**You MUST solder 5.1kΩ resistors from CC1 and CC2 pins to GND.**

This is USB-C specification — without CC pull-downs, the upstream USB-C host will NOT supply 5V on VBUS.

```
USB-C Breakout Wiring:

  VBUS ──────► 5V Rail
  GND ───────► Ground
  CC1 ──┬──► 5.1kΩ ──► GND
  CC2 ──┴──► 5.1kΩ ──► GND
  D+/D- ────► (unused)
```

> **Note:** If your breakout board already has CC resistors built-in, verify with multimeter (should read ~5.1kΩ between CC1/CC2 and GND). Most cheap breakouts do NOT include these.
>
> **💡 Workaround:** You own **4.7kΩ resistors**. If you don't have 5.1kΩ, you can try using your 4.7kΩ ones. They are slightly out of spec but usually work for simple 5V requests. If that fails, you'll need to buy 5.1kΩ.

---

## Part 9: Expansion Capacity

### What You Can Still Add

| Resource | Currently Free | Can Add |
|---|---|---|
| ESP32 #1 GPIOs | 7 pins | Buttons, LEDs, buzzers, more sensors |
| ESP32 #2 GPIOs | 11 pins | Environmental sensors (temp, humidity) |
| ESP32 #2 I2C | Full bus free | OLED display, I2C sensors |
| Level Shifters | 8 spare | More 5V sensors |
| USB-C Breakouts | 4 spare | Additional power injection points |
| Protoboards | 5 spare | More circuit boards |
| PN532 NFC | 1 spare | Second door reader |

### Expansion Examples

| Want to Add | Requirements | Available? |
|---|---|---|
| Status LED on door | 1 GPIO + LED | YES (GPIO 18) |
| Buzzer for feedback | 1 GPIO + buzzer | YES (GPIO 19) |
| Temperature sensor (I2C) | I2C bus | YES (Node B has free I2C) |
| Second NFC reader | 1 PN532 + I2C | YES (spare PN532) |
| Emergency button | 1 GPIO | YES (multiple free) |

---

## Part 10: Checklist

### While Waiting for Delivery
- [ ] Watch soldering tutorials (first-time solderer)
- [ ] Read component datasheets

### After Delivery - Testing Phase
- [ ] Test each ESP32 with blink sketch
- [ ] Test PN532 I2C connection (add 4.7K pull-ups)
- [ ] Test Finger Vein UART (57600 baud)
- [ ] Test TX510 UART (115200 baud)
- [ ] Test Radar UART (256000 baud)
- [ ] Test Relay actuation
- [ ] Test ESP-NOW between two ESP32s

### Build Phase
- [ ] Only after ALL tests pass on breadboard
- [ ] Draw final wiring diagram
- [ ] Label all wires before soldering
- [ ] Solder to protoboard
- [ ] Mount in waterproof box
- [ ] Install cable glands

---

## Documentation Links

### Official Datasheets

| Component | Documentation |
|---|---|
| ESP32 WROOM-32D | [Datasheet (PDF)](https://www.sigmaelectronica.net/wp-content/uploads/2021/11/ESP32-WROOM-32D_pdf.pdf) |
| PN532 NFC | [Adafruit Wiring Guide](https://learn.adafruit.com/adafruit-pn532-rfid-nfc/breakout-wiring) |
| HLK-LD2410C | [HiLink Product Page](https://www.hlktech.net/index.php?id=1095) |
| HLK-LD2410C Protocol | [Serial Protocol (PDF)](http://h.hlktech.com/download/HLK-LD2410C-24G/1/LD2410C%20%E4%B8%B2%E5%8F%A3%E9%80%9A%E4%BF%A1%E5%8D%8F%E8%AE%AE%20V1.09.pdf) |
| Waveshare Finger Vein | [Product Page](https://www.waveshare.com/finger-vein-scanner-module-a.htm) |
| Finger Vein Protocol | [Protocol PDF](https://files.waveshare.com/wiki/Finger_Vein_Scanner_Module_B/Finger_Vein_Module_Communication_Protocol_EN.pdf) |
| HLK-TX510 | [Blakadder Review](https://blakadder.com/hlk-tx510/) |
| HLK-TX510 | [Blakadder GitHub](https://github.com/blakadder/HLK-TX510) |
| Relay Module | [Datasheet (PDF)](https://handsontec.com/dataspecs/relay/1Ch-relay.pdf) |
| Logic Level Converter | [Adafruit Product](https://www.adafruit.com/product/757) |
| NTAG215 | [NXP Datasheet (PDF)](https://www.nxp.com/docs/zh/data-sheet/NTAG213_215_216.pdf) |

### Libraries & Code

| Component | Library |
|---|---|
| PN532 NFC | [Adafruit-PN532](https://github.com/adafruit/Adafruit-PN532) |
| HLK-LD2410 | [ld2410 Library](https://github.com/ncmreynolds/ld2410) |
| ESP-NOW | [Espressif Docs](https://docs.espressif.com/projects/esp-idf/en/latest/esp32/api-reference/network/esp_now.html) |

---

*End of Inventory Document*

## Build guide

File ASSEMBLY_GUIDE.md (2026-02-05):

# Complete Hardware Assembly Guide

> **For Absolute Beginners** - No prior electronics experience required
> 
> Last Updated: February 2026 | SmartCampus Project v2.0

---

## Table of Contents

1. [Before You Begin](#1-before-you-begin)
2. [Safety & ESD Protection](#2-safety--esd-protection)
3. [Your Tools & What They Do](#3-your-tools--what-they-do)
4. [Workspace Setup](#4-workspace-setup)
5. [Understanding Your Components](#5-understanding-your-components)
6. [ESP32 First Boot](#6-esp32-first-boot)
7. [Breadboard Fundamentals](#7-breadboard-fundamentals)
8. [Component Testing - PN532 NFC Reader](#8-component-testing---pn532-nfc-reader)
9. [Component Testing - Relay Module](#9-component-testing---relay-module)
10. [Component Testing - Finger Vein Sensor](#10-component-testing---finger-vein-sensor)
11. [Component Testing - TX510 Face Recognition](#11-component-testing---tx510-face-recognition)
12. [Component Testing - LD2410 Radar](#12-component-testing---ld2410-radar)
13. [Integration Testing - Gatekeeper Node](#13-integration-testing---gatekeeper-node)
14. [Integration Testing - Watchman Node](#14-integration-testing---watchman-node)
15. [ESP-NOW Pairing](#15-esp-now-pairing)
16. [Soldering Tutorial](#16-soldering-tutorial)
17. [Permanent Assembly](#17-permanent-assembly)
18. [Enclosure & Mounting](#18-enclosure--mounting)
19. [Troubleshooting Encyclopedia](#19-troubleshooting-encyclopedia)
20. [Quick Reference Cards](#20-quick-reference-cards)

---

# 1. Before You Begin

## The Golden Rules

```
+===========================================================================+
|                         THE 5 GOLDEN RULES                                 |
+===========================================================================+
|                                                                           |
|  1. POWER OFF before connecting/disconnecting ANYTHING                    |
|                                                                           |
|  2. DOUBLE-CHECK wiring BEFORE powering on                                |
|                                                                           |
|  3. TEST each component INDIVIDUALLY before combining                     |
|                                                                           |
|  4. When in doubt, STOP and ASK                                           |
|                                                                           |
|  5. If something smells burning, UNPLUG IMMEDIATELY                       |
|                                                                           |
+===========================================================================+
```

## What You're Building

You're building a **two-node wireless access control system**:

```
    NODE A (Gatekeeper)                    NODE B (Watchman)
    ==================                     ==================
    Location: Door Frame                   Location: Ceiling
    
    +------------------+                   +------------------+
    |     ESP32 #1     |    ESP-NOW        |     ESP32 #2     |
    |                  | <===============> |                  |
    | + NFC Reader     |    (wireless)     | + Radar Sensor   |
    | + Finger Vein    |                   | + Power Relay    |
    | + Face Camera    |                   |                  |
    | + Door Relay     |                   |                  |
    +--------|---------+                   +--------|---------+
             |                                      |
             v                                      v
        Door Lock                            Room Lights/AC
```

## Estimated Time

| Phase | Time | Difficulty |
|---|---|---|
| ESP32 First Boot | 30 min | Easy |
| Individual Component Tests | 2-3 hours | Easy |
| Integration Tests | 2-3 hours | Medium |
| Soldering & Assembly | 4-6 hours | Medium |
| Enclosure & Mounting | 2-3 hours | Medium |
| **Total** | **10-15 hours** | - |

> **Tip:** Don't rush. Take breaks. Mistakes happen when you're tired.

---

# 2. Safety & ESD Protection

## Electrical Safety

### Voltage Levels in This Project

| Voltage | Source | Danger Level | Components |
|---|---|---|---|
| **5V DC** | USB | Safe | ESP32, NFC, Radar, TX510, Relay coil |
| **3.3V DC** | ESP32 output | Safe | Finger Vein, logic signals |
| **120/240V AC** | Wall outlet | **LETHAL** | Only if connecting real door lock |

> **WARNING:** This guide covers only the LOW VOLTAGE (5V/3.3V) portion.  
> If you need to connect to mains voltage (door locks, AC lights), **hire a licensed electrician**.

### Safety Rules

1. **Never work on a powered circuit** - Always unplug USB before making changes
2. **Keep drinks away** - Water + electronics = bad
3. **Work in good lighting** - You need to see what you're doing
4. **Don't force connections** - If it doesn't fit, you're doing it wrong
5. **Touch ground first** - Discharge static before handling components

## ESD (Electrostatic Discharge) Protection

Your body can hold **thousands of volts** of static electricity. You won't feel it, but it can destroy sensitive electronics instantly.

### The Static Problem

```
You (standing on carpet, wearing socks):  +3,000 volts
ESP32 maximum tolerance:                  ~20 volts

Result: Dead ESP32
```

### How to Protect Your Components

**Minimum Protection (Do This At Least):**
1. Touch a **grounded metal object** before handling any component
   - Metal computer case (while plugged in but off)
   - Metal water pipe
   - Radiator
2. Don't shuffle your feet while working
3. Avoid working on carpet if possible

**Better Protection:**
1. Work on a **wooden or tile floor**
2. Use a **metal table** and touch it frequently
3. Keep components in their **anti-static bags** until needed

**Best Protection (Recommended for Cold/Dry Climates):**
1. Buy an **anti-static wrist strap** (~$5)
2. Clip it to your wrist, connect the other end to:
   - The metal case of a plugged-in computer
   - A grounded outlet's screw
   - Any grounded metal pipe

### Your Anti-Static Routine

Before touching any component:
```
1. Stand up from chair
2. Touch metal table/computer case with whole palm (not just fingertip)
3. Wait 1 second
4. Pick up component by its edges (avoid touching chips)
```

---

# 3. Your Tools & What They Do

## Tools From Your Orders

### Multimeter (ANENG SZ308)

Your **most important tool** for debugging. It measures voltage, current, resistance, and continuity.

```
                    ANENG SZ308 MULTIMETER
                    
                       +-----------+
                       |   LCD     |
                       |  DISPLAY  |
                       +-----------+
                       |           |
    MODE DIAL -------> |  [DIAL]   |
                       |           |
                       +-----+-----+
                             |
              +--------------+---------------+
              |              |               |
           [COM]          [VΩmA]          [10A]
              |              |               |
         Black Probe    Red Probe      (Don't use)
```

**Dial Positions You'll Use:**

| Symbol | What It Measures | When to Use |
|---|---|---|
| **V⎓** (V with ⎓) | DC Voltage | Check power rails (5V, 3.3V) |
| **Ω** | Resistance | Check resistor values, short circuits |
| **)))** (Sound waves) | Continuity | Test if two points are connected |

**How to Use:**
1. Insert **black probe** into **COM** port
2. Insert **red probe** into **VΩmA** port
3. Turn dial to desired mode
4. Touch probes to circuit

### Breadboard (MB-102 Kit)

A board for **temporary circuits** - no soldering required.

```
        MB-102 BREADBOARD LAYOUT
        
    Power Rails (horizontal)
    ========================
    + + + + + + + + + + + + +  <-- Red line = Positive (5V or 3.3V)
    - - - - - - - - - - - - -  <-- Blue line = Ground (GND)
    
    Terminal Strips (vertical)
    ==========================
    a b c d e | | f g h i j
    +---------+ +---------+
    | 1 1 1 1 | | 1 1 1 1 |    <-- Row 1: a-e connected, f-j connected
    | 2 2 2 2 | | 2 2 2 2 |    <-- Row 2: a-e connected, f-j connected
    | 3 3 3 3 | | 3 3 3 3 |    <-- Row 3: etc...
    |   ...   | |   ...   |
    | 30 30 30| |30 30 30 |
    +---------+ +---------+
       GAP (not connected)
```

**Key Concepts:**
- **Power rails** (+ and -) run **horizontally** across the board
- **Terminal strips** (a-e and f-j) run **vertically** in groups of 5
- The **center gap** separates left and right - they're NOT connected
- Push components' legs into holes - they grip automatically

### Soldering Iron (80W)

For **permanent connections** after testing works on breadboard.

```
                SOLDERING IRON ANATOMY
                
    Handle                 Heating Element    Tip
    [=====================================]====>
                |
                v
           Temperature
           Control Dial
```

**Temperature Settings:**
| Material | Temperature |
|---|---|
| Thin wires, small components | 300-320°C |
| Thick wires, large pads | 350-380°C |
| Lead-free solder (harder) | 370-400°C |

> **You won't use this until Phase 4 (Permanent Assembly)**. Focus on breadboard testing first.

### Dupont Wires

Pre-made jumper wires with connectors on each end:

```
    DUPONT WIRE TYPES
    
    Female-to-Female (F-F)        Male-to-Male (M-M)
    [===]----------[===]          |---|----------|---|
    
    Use F-F for:                  Use M-M for:
    - Connecting TO modules       - Breadboard connections
    - Sensor connections          - Bridging power rails
```

### USB-C Cables

You have 2 USB-C cables. Keep them labeled:

```
    Cable #1: "ESP32 #1" (Gatekeeper)
    Cable #2: "ESP32 #2" (Watchman)
```

> **Important:** Not all USB-C cables are equal. Your cables are **data cables** (can transfer data).  
> Cheap cables are often **charge-only** (won't work for programming).

---

# 4. Workspace Setup

## Ideal Setup

```
+===========================================================================+
|                           WORKSPACE LAYOUT                                 |
+===========================================================================+
|                                                                           |
|     +----------------+          +-------------------+                     |
|     |    COMPUTER    |          |   WELL-LIT AREA   |                     |
|     |  (Serial Mon.) |          |   (your work)     |                     |
|     +-------+--------+          +-------------------+                     |
|             |                            |                                |
|             |   USB Cable                |                                |
|             +----------------------------+                                |
|                                                                           |
|     +------------------+    +------------------+    +------------------+  |
|     | COMPONENT TRAY   |    |   BREADBOARD     |    |    MULTIMETER    |  |
|     | (organized)      |    |   (work area)    |    |   (within reach) |  |
|     +------------------+    +------------------+    +------------------+  |
|                                                                           |
|     +------------------------------------------------------------------+  |
|     |                    ANTI-STATIC MAT (optional)                     |  |
|     +------------------------------------------------------------------+  |
|                                                                           |
+===========================================================================+
```

## Minimum Requirements

- [ ] **Good lighting** - desk lamp or window
- [ ] **Flat, stable surface** - not your bed
- [ ] **Computer nearby** - for Serial Monitor
- [ ] **Phone/tablet** - to read this guide while working
- [ ] **Small containers** - to organize parts (egg cartons work great)

## Organize Your Components

Before starting, lay out all your components:

```
+-----------------------------------------------------------------------+
|  TRAY 1: Controllers          |  TRAY 2: Sensors                      |
|  - ESP32 #1                   |  - PN532 NFC Module                   |
|  - ESP32 #2                   |  - Finger Vein Sensor                 |
|  - USB-C Cables               |  - TX510 Face Module                  |
|                               |  - LD2410 Radar                       |
+-----------------------------------------------------------------------+
|  TRAY 3: Actuators            |  TRAY 4: Wiring & Misc                |
|  - Relay Module #1            |  - Dupont Wires (F-F and M-M)         |
|  - Relay Module #2            |  - Resistors (4.7K)                   |
|  - NFC Cards (NTAG215)        |  - USB-C Breakout Boards              |
|                               |  - Breadboard + Power Module          |
+-----------------------------------------------------------------------+
```

---

# 5. Understanding Your Components

## ESP32 WROOM-32D

Your **main microcontroller** - the brain of each node.

```
                         ESP32 WROOM-32D PINOUT
                         
                             ANTENNA
                           ___________
                          |           |
              EN/RST ----o|           |o---- GPIO23
             GPIO36 -----o|           |o---- GPIO22  (I2C SCL)
             GPIO39 -----o|           |o---- GPIO1   (TX0)
             GPIO34 -----o|           |o---- GPIO3   (RX0)
             GPIO35 -----o|           |o---- GPIO21  (I2C SDA)
             GPIO32 -----o|           |o---- GND
             GPIO33 -----o|   ESP32   |o---- GPIO19
             GPIO25 -----o|           |o---- GPIO18
             GPIO26 -----o|           |o---- GPIO5
             GPIO27 -----o|           |o---- GPIO17  (UART2 TX)
             GPIO14 -----o|           |o---- GPIO16  (UART2 RX)
             GPIO12 -----o|           |o---- GPIO4
                GND -----o|           |o---- GPIO2   (Built-in LED)
             GPIO13 -----o|           |o---- GPIO15
               SD2  -----o|           |o---- SD1
               SD3  -----o|   USB-C   |o---- SD0
               CMD  -----o|___________|o---- CLK
                                |
                            +---+---+
                            | USB-C |
                            +-------+
                           
        3V3 -----o                         o----- VIN (5V input)
        GND -----o                         o----- GND
```

**Power Options:**
| Pin | Voltage | When to Use |
|-----|---|---|
| **VIN** | 5V | Powering via USB or external 5V supply |
| **3V3** | 3.3V | Output - powers 3.3V sensors |
| **GND** | Ground | Always connect to circuit ground |

**GPIOs We Use:**

| GPIO | Function in Gatekeeper | Function in Watchman |
|---|---|---|
| 21 | I2C SDA (NFC) | - |
| 22 | I2C SCL (NFC) | - |
| 16 | UART2 RX (Finger Vein) | UART2 RX (Radar) |
| 17 | UART2 TX (Finger Vein) | UART2 TX (Radar) |
| 4 | UART1 RX (TX510 Face) | - |
| 5 | UART1 TX (TX510 Face) | - |
| 25 | Relay Control | - |
| 26 | - | Relay Control |
| 2 | Built-in LED | Built-in LED |

**GPIOs to Avoid:**
| GPIO | Why |
|---|-----|
| 0, 1, 3 | Used for boot/serial |
| 6-11 | Connected to flash memory |
| 12 | Boot mode (must be LOW at boot) |

## PN532 NFC Module

**Purpose:** Reads NFC cards (NTAG215) and phone NFC signals.

```
                    PN532 NFC MODULE V3
                    
    +-------------------------------------------+
    |                                           |
    |   +-------+     +------------------+      |
    |   |  MCU  |     |   NFC ANTENNA    |      |
    |   +-------+     |                  |      |
    |                 |   (coil area)    |      |
    |                 +------------------+      |
    |                                           |
    |  [LED]                                    |
    |                                           |
    +-----+-------------------------------------+
          |
    +-----+-----+
    |  DIP SW   |   <-- Mode selection switches
    |  1   2    |
    +-----+-----+
          |
    +-----+-------------------------------------------+
    | VCC | GND | SDA | SCL | RSTPDN | IRQ | RQST    |
    +-----+-----+-----+-----+--------+-----+---------+
      5V   GND  Data  Clock  (unused for I2C mode)
```

**DIP Switch Settings for I2C Mode:**
```
    +-------+
    | 1 | 2 |
    +---+---+
    |OFF|ON |  <-- This is correct for I2C
    +---+---+
```

## Relay Module (5V 1-Channel)

**Purpose:** Switches high-power devices (door lock, lights) using low-power signal.

```
                    5V RELAY MODULE
                    
    Control Side (Low Voltage)      Load Side (High Voltage)
    ==========================      ========================
    
    +---------------------------+---+---+---+
    |                           |COM|NC |NO |
    |   +-----+                 +---+---+---+
    |   |RELAY|                   |   |   |
    |   |     |                   |   |   +--- Normally Open
    |   +-----+                   |   +------- Normally Closed
    |                             +----------- Common
    |   [LED] [LED]                           
    |   PWR   ACTIVE                          
    +-------+-------+-------+                 
            |       |       |                 
          [VCC]   [GND]   [IN]                
            |       |       |                 
           5V     Ground  Signal              
                          (GPIO)              
```

**Terminals Explained:**
| Terminal | Meaning | State When Relay OFF | State When Relay ON |
|---|---|---|---|
| **COM** | Common | - | - |
| **NC** | Normally Closed | Connected to COM | Disconnected |
| **NO** | Normally Open | Disconnected | Connected to COM |

**For Door Lock (Fail-Safe):**
- Connect lock between **COM** and **NC**
- When power fails, door **unlocks** (fire safety)

## Waveshare Finger Vein Sensor

**Purpose:** Biometric authentication using finger vein patterns (more secure than fingerprint).

```
                FINGER VEIN SENSOR MODULE (A)
                
    +-----------------------------------------+
    |                                         |
    |   +---------------+     +-----------+   |
    |   |    IR LEDs    |     | PROCESSOR |   |
    |   +---------------+     +-----------+   |
    |                                         |
    |   +---------------+                     |
    |   |    CAMERA     |                     |
    |   +---------------+                     |
    |                                         |
    |   [====== FINGER SLOT ======]           |
    |                                         |
    +----+-----+-----+-----+----+-----+-------+
         |     |     |     |    |     |
        VCC   GND   TXD   RXD  IRQ  WAKEUP
         |     |     |     |
       3.3V   GND   -->   <--
                    to    from
                  ESP32  ESP32
```

> **CRITICAL:** This module runs on **3.3V ONLY**.  
> Connecting 5V will **permanently damage** it!

**UART Settings:**
- Baud Rate: 57600
- Data Bits: 8
- Stop Bits: 1
- Parity: None

## HLK-TX510 Face Recognition

**Purpose:** 3D face recognition with infrared liveness detection (prevents photo spoofing).

```
                    HLK-TX510 MODULE (with Test Kit)
                    
    +------------------------------------------------+
    |                                                |
    |  +--------+  +--------+  +--------+            |
    |  |  RGB   |  | 3D IR  |  |  LCD   |            |
    |  | Camera |  | Camera |  |Display |            |
    |  +--------+  +--------+  +--------+            |
    |                                                |
    |                                                |
    |  [USB-C]    [Speaker]                          |
    |                                                |
    +-------+----+----+----+----+----+---------------+
            |    |    |    |    |    |
           VCC  GND  TX   RX  ...   ...
            |    |    |    |
           5V   GND   |    |
                      |    |
               to GPIO4   from GPIO5
               (ESP RX)   (ESP TX)
```

**Power Requirements:**
- Voltage: **5V**
- Current: **500-800mA peak** (needs external power, not from ESP32)

**UART Settings (UART1 on pins 38/39):**
- Baud Rate: 115200
- Data Bits: 8
- Stop Bits: 1
- Parity: None

## HLK-LD2410C Radar

**Purpose:** Detects human presence using 24GHz mmWave radar (works through walls, in darkness).

```
                    HLK-LD2410C RADAR
                    
    +------------------------+
    |                        |
    |   [=== ANTENNA ===]    |   <-- Radar detection area
    |                        |       (up to 5 meters)
    |   +----------------+   |
    |   |   PROCESSOR    |   |
    |   +----------------+   |
    |                        |
    +---+----+----+----+-----+
        |    |    |    |
       VCC  GND  TX   RX
        |    |    |    |
       5V   GND   |    |
                  |    |
           to GPIO16  from GPIO17
           (ESP RX)   (ESP TX)
```

> **CRITICAL:** This module requires **5V power**.  
> It will NOT work on 3.3V!

**UART Settings:**
- Baud Rate: 256000
- Data Bits: 8
- Stop Bits: 1
- Parity: None

---

# 6. ESP32 First Boot

## What You'll Achieve

By the end of this section, you will:
- [ ] Have PlatformIO installed
- [ ] Successfully connect ESP32 to your computer
- [ ] Upload a "blink" program
- [ ] See output in Serial Monitor

## Step 6.1: Install Software

### Install VS Code

1. Download from: https://code.visualstudio.com/
2. Install with default options
3. Launch VS Code

### Install PlatformIO Extension

1. In VS Code, click the **Extensions** icon (left sidebar, looks like 4 squares)
2. Search for "**PlatformIO IDE**"
3. Click **Install**
4. Wait for installation (may take 5-10 minutes)
5. Restart VS Code when prompted

```
    VS Code with PlatformIO
    
    +--------------------------------------------------+
    |  File  Edit  View  ...                           |
    +--------------------------------------------------+
    |     |                                            |
    | [E] |    Welcome to PlatformIO!                  |
    | [X] |                                            |
    | [P] | <-- PlatformIO icon (ant/alien head)       |
    |     |                                            |
    +--------------------------------------------------+
```

### Install USB Driver (if needed)

Your ESP32 uses a **CH340** USB-to-serial chip. Most modern systems auto-install drivers, but if it doesn't work:

**Windows:**
1. Download CH340 driver: https://www.wch.cn/downloads/CH341SER_EXE.html
2. Run installer
3. Restart computer

**Mac:**
1. Usually works automatically on macOS 10.12+
2. If not: https://www.wch.cn/downloads/CH341SER_MAC_ZIP.html

## Step 6.2: First Connection

### Connect ESP32

1. **Pick up ESP32 by edges** (avoid touching the metal shield)
2. Plug USB-C cable into ESP32
3. Plug other end into your computer
4. Look for:
   - Red LED on ESP32 (power indicator)
   - On Windows: "ding" sound for new device

### Find the COM Port

**Windows:**
1. Open **Device Manager** (search in Start menu)
2. Expand "**Ports (COM & LPT)**"
3. Look for "**USB-SERIAL CH340 (COM#)**"
4. Note the COM number (e.g., COM3)

```
    Device Manager
    
    > Audio inputs and outputs
    > Bluetooth
    v Ports (COM & LPT)
        USB-SERIAL CH340 (COM3)  <-- This is your ESP32
    > Processors
```

**Mac:**
1. Open Terminal
2. Type: `ls /dev/tty.usb*`
3. Look for something like `/dev/tty.usbserial-1420`

**If you don't see it:**
- Try a different USB port
- Try a different USB-C cable (some are charge-only)
- Install the CH340 driver (see above)

## Step 6.3: Create Test Project

### Create New Project

1. Click the **PlatformIO** icon (left sidebar)
2. Click "**PIO Home**" > "**Open**"
3. Click "**+ New Project**"

```
    New Project Settings:
    
    Name:           ESP32_Blink_Test
    Board:          Espressif ESP32 Dev Module
    Framework:      Arduino
    Location:       [Use default or choose folder]
```

4. Click "**Finish**" (wait for project creation)

### Write Blink Code

1. Open the project in `firmware/tests/01_esp32_blink` using VS Code.
2. Review the code in `src/main.cpp`. It's designed to verify your ESP32's basic functionality and show its MAC address.
3. Save the file if you made any changes.

### Upload the Code

1. Click the **checkmark** icon in the bottom toolbar (Build)
2. Wait for "SUCCESS" message
3. Click the **arrow** icon in the bottom toolbar (Upload)
4. Watch the progress...

```
    PlatformIO Toolbar (bottom of VS Code):
    
    [✓] [→] [🔌] [🗑️]
     |   |    |    |
    Build  Upload  Serial Monitor  Clean
```

**Expected Upload Output:**
```
Connecting........_____
Chip is ESP32-D0WDQ6 (revision 1)
Uploading stub...
Running stub...
Changing baud rate to 921600
Changed.
Writing at 0x00001000... (100 %)
Writing at 0x00008000... (100 %)
Writing at 0x0000e000... (100 %)
Writing at 0x00010000... (100 %)
Leaving...
Hard resetting via RTS pin...
=== [SUCCESS] ===
```

## Step 6.4: Open Serial Monitor

1. Click the **plug** icon in the bottom toolbar (Serial Monitor)
2. Or press: `Ctrl+Alt+S` (Windows) / `Cmd+Shift+P` > "PlatformIO: Monitor"
3. **Check baud rate is 115200** (bottom right of monitor window)

**Expected Output:**
```
========================================
ESP32 Blink Test
========================================
Chip Model: ESP32-D0WDQ6
Chip Revision: 1
Flash Size: 4 MB
Free Heap: 294 KB
MAC Address: 24:6F:28:XX:XX:XX
========================================
LED should be blinking now...

LED: ON
LED: OFF
LED: ON
LED: OFF
...
```

### Verify LED is Blinking

Look at your ESP32 board:
- The **blue LED** (near GPIO2) should blink every 500ms
- If the red LED is on but blue isn't blinking, there's a problem

## Step 6.5: Troubleshooting First Boot

| Problem | Cause | Solution |
|---|---|---|
| "No COM port found" | Driver not installed | Install CH340 driver |
| "Failed to connect" | ESP32 not in boot mode | Hold BOOT button while uploading |
| "Permission denied" | Port in use | Close other programs using serial |
| Upload starts but hangs | Cable issue | Try different USB cable |
| Serial Monitor shows garbage | Wrong baud rate | Set to 115200 |
| No LED blinking | Wrong pin | Some boards use different LED pin |

### The BOOT Button Trick

If uploads fail, try this:
1. Click Upload
2. When you see "Connecting........", **hold the BOOT button** on ESP32
3. Keep holding until upload starts
4. Release BOOT button

```
                     ESP32 Buttons
                     
    [EN/RST]                    [BOOT]
       |                           |
    Restarts                   Hold during
    the board                  "Connecting..."
```

## Checkpoint: First Boot Complete

Before proceeding, verify:
- [ ] ESP32 LED is blinking
- [ ] Serial Monitor shows chip info
- [ ] You see "LED: ON" / "LED: OFF" messages
- [ ] You noted the MAC address (you'll need it later)

> **Write down your MAC address:**  
> ESP32 #1: `__:__:__:__:__:__`  
> (Do the same for ESP32 #2 later)

---

# 7. Breadboard Fundamentals

## How a Breadboard Works

The MB-102 breadboard has **internal metal strips** that connect certain holes:

```
            BREADBOARD INTERNAL CONNECTIONS
            
     Power Rails (horizontal connections)
     =====================================
     
     + + + + + + + + + + + + + + + + + + + + + + + + + +
     |_______________________________________________|  <-- All connected!
     
     - - - - - - - - - - - - - - - - - - - - - - - - - -
     |_______________________________________________|  <-- All connected!

     Terminal Area (vertical connections)
     ====================================
     
        a   b   c   d   e       f   g   h   i   j
     +---+---+---+---+---+     +---+---+---+---+---+
     | 1 | 1 | 1 | 1 | 1 |     | 1 | 1 | 1 | 1 | 1 |  Row 1
     |___|___|___|___|___|     |___|___|___|___|___|
          Connected               Connected
          
     | 2 | 2 | 2 | 2 | 2 |     | 2 | 2 | 2 | 2 | 2 |  Row 2
     |___|___|___|___|___|     |___|___|___|___|___|
     
                   GAP - NOT CONNECTED
```

**Key Rules:**
1. Power rails (+/-) run **horizontally** - great for distributing power
2. Terminal rows run **vertically** in groups of 5 (a-e and f-j)
3. **Center gap** separates left and right sides
4. A chip straddles the gap so each pin is isolated

## Setting Up Power Rails

### Power Module (from MB-102 kit)

Your kit includes a power module that provides regulated 5V and 3.3V:

```
          MB-102 POWER MODULE
          
    +---------------------------+
    |   [5V] [OFF] [3.3V]      |  <-- Voltage selectors (jumpers)
    |         LEFT  RIGHT       |      Set BOTH to 5V for now
    +---------------------------+
    |   [USB]       [DC Jack]   |  <-- Power input options
    +---------------------------+
            |           |
            |  Pins     |
            v           v
    +-----+-----+-----+-----+
    |  +  |  -  |  +  |  -  |  <-- These plug into breadboard
    +-----+-----+-----+-----+     power rails
```

### Setting Up Power

1. **Set both jumpers to 5V** (for now)
2. **Plug the power module** into the breadboard power rails:
   - The 4 pins should fit into + - + - of the power rails
   - Make sure + goes to + and - goes to -!

3. **Connect a USB cable** to the power module (not yet - do this after wiring)

```
    BREADBOARD WITH POWER MODULE
    
    +---[POWER MODULE]---+
    |                    |
    v                    v
    + + + + + + + + + + + +  <-- 5V (red)
    - - - - - - - - - - - -  <-- GND (blue)
    
    a b c d e   f g h i j
    [... terminal area ...]
    
    - - - - - - - - - - - -  <-- GND (blue)
    + + + + + + + + + + + +  <-- 5V (red)
```

### Verify Power with Multimeter

**Before connecting any components:**

1. Turn on multimeter, set to **V⎓** (DC Voltage)
2. Touch **black probe** to any **-** (blue) hole
3. Touch **red probe** to any **+** (red) hole
4. Display should show **~5.0V** (4.8-5.2V is acceptable)

```
    MEASURING VOLTAGE
    
                        Multimeter
                      +-----------+
                      |   5.02V   |
                      +-----------+
                           / \
                    red   /   \ black
                    probe/     \probe
                        /       \
                       +         -
    Power Rail:  + + + + + + + + - - - - - - - -
```

---

# 8. Component Testing - PN532 NFC Reader

## What You'll Achieve

By the end of this section, you will:
- [ ] Wire PN532 to ESP32 correctly
- [ ] Add required pull-up resistors
- [ ] Read an NFC card's UID
- [ ] Understand I2C communication

## Understanding I2C

I2C (Inter-Integrated Circuit) is a communication protocol using just 2 wires:
- **SDA** (Serial Data): Carries the actual data
- **SCL** (Serial Clock): Keeps sender and receiver in sync

```
    I2C COMMUNICATION
    
    ESP32 (Master)              PN532 (Slave)
    +-------------+             +-------------+
    |             |    SDA      |             |
    |         SDA |------------>|  SDA        |
    |             |    SCL      |             |
    |         SCL |------------>|  SCL        |
    +-------------+             +-------------+
                    
                 Both lines need PULL-UP resistors!
```

**Why Pull-Up Resistors?**
- I2C lines are "open-drain" - they can only pull LOW
- Pull-up resistors bring them HIGH when not actively driven
- Without them: random failures, no communication

## Wiring Diagram

```
                    PN532 NFC to ESP32 WIRING
                    
                                        +3.3V (from ESP32)
                                          |
                                    +-----+-----+
                                    |           |
                              [4.7K]R1    [4.7K]R2   <-- Pull-up resistors
                                    |           |
    PN532               +-----------+-----------+
    +-------+           |           |           |
    |  VCC  |-----------+-----------|-----------|------ VIN (5V from ESP32)
    |  GND  |------------------------------------ GND (ESP32)
    |  SDA  |----------------------------------+- GPIO21 (ESP32)
    |  SCL  |-----------------------------+      GPIO22 (ESP32)
    +-------+                             |
                                          +------ (also to R1)
```

### Step-by-Step Wiring

**What You Need:**
- ESP32 (already tested from Section 6)
- PN532 NFC Module
- 2x 4.7K resistors (from your order)
- 4x Female-to-Female Dupont wires

**Step 1: Set DIP Switches**

On the back of the PN532, find the DIP switches:
```
    DIP SWITCH SETTINGS
    
    +-------+
    | 1 | 2 |
    +---+---+
    |OFF|ON |  <-- Correct for I2C mode
    +---+---+
      ^   ^
      |   |
    Down  Up
```

**Step 2: Wire Power**

```
    Connection 1: PN532 VCC → ESP32 VIN (5V)
    Connection 2: PN532 GND → ESP32 GND
```

**Step 3: Wire Data Lines**

```
    Connection 3: PN532 SDA → ESP32 GPIO21
    Connection 4: PN532 SCL → ESP32 GPIO22
```

**Step 4: Add Pull-Up Resistors (Maybe)**

> **IMPORTANT: Check your specific board first!**
> 
> Your PN532 V3 module from AliExpress may already have built-in pull-up resistors.
> 
> **Before adding external pull-ups:**
> 1. Try connecting WITHOUT any external resistors first
> 2. Run the NFC test sketch
> 3. If it works → you don't need external pull-ups (your board has them built-in)
> 4. If "PN532 not found" → add 4.7K pull-ups as shown below
> 5. Still not working? → try two 4.7K in parallel (~2.35K) for stronger pull-up
>
> Many generic PN532 boards have onboard pull-ups. Adding more can actually cause problems.

**If you need to add pull-ups**, the 4.7K resistors look like this:
```
    4.7K Resistor Color Code:
    
    +----[////]----+
    |  Y  V  R  G  |
    |  e  i  e  o  |
    |  l  o  d  l  |
    |  l  l     d  |
    |  o  e        |
    |  w  t        |
    +----[////]----+
    
    Yellow = 4
    Violet = 7
    Red = x100
    Gold = ±5%
    
    = 47 × 100 = 4700Ω = 4.7KΩ
```

**On Breadboard:**
```
    Pull-Up Resistor Placement
    
                3.3V rail (use a wire from ESP32 3V3 pin)
    + + + + + + + + + + + + + + + + +
              |           |
           [4.7K]      [4.7K]
              |           |
    - - - - - | - - - - - | - - - - -
              |           |
          SDA wire    SCL wire
          (GPIO21)    (GPIO22)
```

Alternatively, if not using breadboard:
1. Twist one leg of each resistor together
2. Connect twisted legs to 3.3V
3. Connect other leg of R1 to SDA wire
4. Connect other leg of R2 to SCL wire

### Complete Wiring Checklist

| PN532 Pin | → | ESP32 Pin | Wire Color (suggested) |
|---|---|---|---|
| VCC | → | VIN (5V) | Red |
| GND | → | GND | Black |
| SDA | → | GPIO21 | Blue |
| SCL | → | GPIO22 | Green |
| - | - | - | - |
| 4.7K R1 | between | SDA ↔ 3.3V | - |
| 4.7K R2 | between | SCL ↔ 3.3V | - |

## Test Program

1. Open the project in `firmware/tests/02_nfc_reader` using VS Code.
2. Build and Upload the code to your ESP32.
3. Open Serial Monitor (115200 baud).

## Expected Output

**On Startup:**
```
========================================
PN532 NFC Reader Test
========================================

Found PN532 Firmware: 1.6

SUCCESS: PN532 initialized!

Hold an NFC card near the reader...
========================================
```

**When You Tap a Card:**
```
----------------------------------------
Card detected! UID Length: 7 bytes
UID: 04:A3:2B:1C:7D:00:00
UID (decimal): 4.163.43.28.125.0.0
----------------------------------------
```

## Troubleshooting

| Problem | Cause | Solution |
|---|---|---|
| "PN532 not found" | Wiring error | Double-check SDA/SCL connections |
| "PN532 not found" | DIP switches wrong | Set: 1=OFF, 2=ON |
| "PN532 not found" | Missing pull-ups | Add 4.7K resistors to 3.3V |
| "PN532 not found" | Bad I2C address | Try adding `Wire.begin(21, 22)` before nfc.begin() |
| Card not detected | Card too far | Hold within 2cm of reader |
| Card not detected | Wrong card type | Must be ISO14443A (NTAG215, MIFARE) |
| Intermittent reads | Loose connections | Check all wire connections |
| Garbage in serial | Wrong baud rate | Set to 115200 |

## Checkpoint: NFC Complete

Before proceeding, verify:
- [ ] PN532 found on startup (shows firmware version)
- [ ] NTAG215 card UID is read correctly
- [ ] Multiple cards can be read
- [ ] No "not found" errors after power cycling

> **Write down a card UID for later testing:**  
> Card 1: `__:__:__:__:__:__:__`

---

# 9. Component Testing - Relay Module

## What You'll Achieve

By the end of this section, you will:
- [ ] Wire relay to ESP32 correctly
- [ ] Understand relay trigger modes (HIGH vs LOW)
- [ ] Make relay click on command
- [ ] Verify relay switching with multimeter

## Understanding Relays

A relay is an **electrically controlled switch**. A small current (from ESP32) controls a large current (door lock, lights).

```
    RELAY OPERATION
    
    +------------------+        +------------------+
    | GPIO25 = LOW     |        | GPIO25 = HIGH    |
    |                  |        |                  |
    |   +------+       |        |   +------+       |
    |   |COIL  | OFF   |        |   |COIL  | ON    |
    |   |  O   |       |   -->  |   |  O   |       |
    |   +------+       |        |   +------+       |
    |                  |        |                  |
    |   COM --+        |        |   COM --+        |
    |         |        |        |         |        |
    |   NC ---+        |        |   NC    |        |
    |   NO             |        |   NO ---+        |
    +------------------+        +------------------+
```

**Terminal Behavior:**
| GPIO25 | Relay State | COM-NC | COM-NO |
|---|---|---|---|
| LOW | OFF (coil not energized) | Connected | Open |
| HIGH | ON (coil energized) | Open | Connected |

## Check Your Relay Type

Most cheap relays are "**Active LOW**" - they turn ON when the signal is LOW. Check your relay module:

**Active HIGH (less common):**
- IN pin needs HIGH (3.3V) to activate
- LED labeled "Active: HIGH" or no label

**Active LOW (more common):**
- IN pin needs LOW (GND) to activate
- May have "L" or "Low" marking
- Often has a transistor circuit

**How to Check:**
1. Power the relay (VCC to 5V, GND to GND)
2. Touch IN pin to GND briefly
3. If relay clicks, it's **Active LOW**
4. If nothing happens, touch IN to VCC
5. If relay clicks, it's **Active HIGH**

> Most modules from AliExpress are **Active HIGH** (simpler design).

## Wiring Diagram

```
                    RELAY to ESP32 WIRING
                    
    RELAY MODULE                          ESP32
    +------------+                    +-----------+
    |            |                    |           |
    |    VCC     |--------------------| VIN (5V)  |
    |            |                    |           |
    |    GND     |--------------------| GND       |
    |            |                    |           |
    |    IN      |--------------------| GPIO25    |
    |            |                    |           |
    +------------+                    +-----------+
    
    For testing, leave COM/NC/NO disconnected.
    We'll just listen for the click.
```

### Step-by-Step Wiring

**What You Need:**
- ESP32 (from earlier)
- 5V Relay Module
- 3x Female-to-Female Dupont wires

**Connections:**

| Relay Pin | → | ESP32 Pin | Wire Color (suggested) |
|---|---|---|---|
| VCC | → | VIN (5V) | Red |
| GND | → | GND | Black |
| IN | → | GPIO25 | Yellow or Orange |

## Test Program

1. Open the project in `firmware/tests/03_relay` using VS Code.
2. Build and Upload the code to your ESP32.
3. Open Serial Monitor (115200 baud).

## Expected Results

**What You Should See/Hear:**

1. **Relay LED**: Should toggle on/off every 2 seconds
2. **Click Sound**: Audible mechanical click when switching
3. **Serial Monitor**: "Relay: ON" / "Relay: OFF" alternating

**If Relay is Active LOW**, reverse the logic:
```cpp
digitalWrite(RELAY_PIN, LOW);   // Relay ON
digitalWrite(RELAY_PIN, HIGH);  // Relay OFF
```

## Verify with Multimeter

To confirm the relay is actually switching:

1. Set multimeter to **Continuity mode** (sound wave symbol)
2. Touch probes to **COM** and **NO** terminals
3. When relay is OFF: No beep (no connection)
4. When relay is ON: Beep! (connection made)

```
    TESTING RELAY SWITCHING
    
                 Multimeter
               +-----------+
               |   )))     |  <-- Continuity mode
               +-----------+
                    / \
            Black  /   \ Red
            probe /     \ probe
                 /       \
    RELAY:   [COM]     [NO]
```

## Troubleshooting

| Problem | Cause | Solution |
|---|---|---|
| No click, no LED | Wrong wiring | Check VCC, GND, IN connections |
| LED on, no click | Faulty relay | Try different relay module |
| Click but not switching | Relay stuck | Replace relay |
| Always clicking rapidly | Code issue | Check your loop timing |
| Relay too hot | Wrong voltage | Verify 5V (not 12V) |

## Checkpoint: Relay Complete

Before proceeding, verify:
- [ ] Relay clicks audibly when GPIO25 goes HIGH
- [ ] Relay LED turns on/off correctly
- [ ] Multimeter confirms COM-NO switching
- [ ] Relay works consistently (no random behavior)

---

# 10. Component Testing - Finger Vein Sensor

## What You'll Achieve

By the end of this section, you will:
- [ ] Wire Finger Vein sensor safely (3.3V!)
- [ ] Communicate via UART
- [ ] Verify sensor is responding
- [ ] Enroll a test finger

## CRITICAL: Voltage Warning

```
+===========================================================================+
|                                                                           |
|   ⚠️ WARNING: FINGER VEIN SENSOR IS 3.3V ONLY! ⚠️                         |
|                                                                           |
|   Connecting 5V will PERMANENTLY DESTROY the sensor!                     |
|                                                                           |
|   Double-check BEFORE connecting power:                                   |
|   - VCC must go to ESP32's 3V3 pin (NOT VIN/5V)                          |
|   - Use a multimeter to verify voltage                                    |
|                                                                           |
+===========================================================================+
```

## Wiring Diagram

```
                FINGER VEIN to ESP32 WIRING
                
    FINGER VEIN                           ESP32
    +-----------+                     +-----------+
    |           |                     |           |
    |   VCC     |---------------------| 3V3       |  <-- NOT 5V!
    |           |                     |           |
    |   GND     |---------------------| GND       |
    |           |                     |           |
    |   TXD     |---------------------| GPIO16    |  (ESP32 RX2)
    |           |                     |           |
    |   RXD     |---------------------| GPIO17    |  (ESP32 TX2)
    |           |                     |           |
    +-----------+                     +-----------+
    
    Note: TX from sensor goes to RX on ESP32 (and vice versa)
    This is called "cross-connection" - it's correct!
```

### Understanding TX/RX

This is the most common source of confusion:

```
    UART COMMUNICATION
    
    Device A                    Device B
    +--------+                  +--------+
    |        |                  |        |
    |   TX   |----------------->|   RX   |
    |        |                  |        |
    |   RX   |<-----------------|   TX   |
    |        |                  |        |
    +--------+                  +--------+
    
    TX (Transmit) sends data
    RX (Receive) receives data
    
    A's TX connects to B's RX
    A's RX connects to B's TX
```

### Step-by-Step Wiring

**What You Need:**
- ESP32 (from earlier)
- Waveshare Finger Vein Sensor
- 4x Female-to-Female Dupont wires

**Connections:**

| Finger Vein Pin | → | ESP32 Pin | Wire Color (suggested) |
|---|---|---|---|
| VCC | → | **3V3** (NOT 5V!) | Red |
| GND | → | GND | Black |
| TXD | → | GPIO16 (RX2) | Green |
| RXD | → | GPIO17 (TX2) | Yellow |

**Before Powering On - Verify:**
1. Set multimeter to DC Voltage
2. Touch probes to the VCC wire and GND
3. Power on ESP32
4. Verify reading is ~3.3V (NOT 5V!)

## Test Program

1. Open the project in `firmware/tests/04_finger_vein` using VS Code.
2. Build and Upload the code to your ESP32.
3. Open Serial Monitor (115200 baud).

## Expected Output

**Success:**
```
========================================
Finger Vein Sensor Test
========================================

Testing connection to Finger Vein Sensor...

Sending command: 0x0F

SUCCESS! Sensor responded!

Response (17 bytes):
EF 01 FF FF FF FF 07 00 07 00 00 01 00 00 00 03 0B 

Confirmation Code: 0x00 (Success)

========================================
Finger Vein sensor is working!
========================================
```

**Failure:**
```
ERROR: No response from sensor!

Troubleshooting:
1. Check VCC is connected to 3.3V (NOT 5V!)
2. Check TX/RX are cross-connected correctly
3. Check GND is connected
4. Try power cycling the sensor
5. Look for green LED inside sensor
```

## Troubleshooting

| Problem | Cause | Solution |
|---|---|---|
| No response | TX/RX swapped | Swap GPIO16 and GPIO17 wires |
| No response | Wrong voltage | Verify 3.3V with multimeter |
| No response | Wrong baud rate | Must be 57600 |
| No response | Loose connection | Reseat all wires |
| Sensor feels hot | Connected to 5V | **STOP! May be damaged** |
| Green LED not on | No power | Check VCC/GND connection |

## Checkpoint: Finger Vein Complete

Before proceeding, verify:
- [ ] Sensor responds to test command
- [ ] Confirmation code is 0x00 (success)
- [ ] Sensor stays cool (not hot)
- [ ] Green LED visible inside sensor

---

# 11. Component Testing - TX510 Face Recognition

## What You'll Achieve

By the end of this section, you will:
- [ ] Understand TX510 power requirements
- [ ] Set up external power via USB-C breakout
- [ ] Wire TX510 to ESP32
- [ ] Verify communication

## Power Requirements

The TX510 is power-hungry:
- **Voltage:** 5V
- **Current:** 500-800mA peak

The ESP32's 3.3V regulator can only supply ~500mA total, and the VIN pin shares this with the ESP32 itself. **We need external power.**

## USB-C Breakout Setup

Your USB-C breakout boards let you tap into a USB power source directly:

```
              USB-C BREAKOUT BOARD
              
    +------+       +------------------+
    | USB  |       |                  |
    | Type |=======| VBUS  GND        |
    |  C   |       |  +     -         |
    +------+       | CC1   CC2        |
                   +------------------+
                          |
    Connect to:    5V    GND
    power source   rail  rail
```

### CC Resistors (Critical!)

USB-C requires **pull-down resistors** on CC1 and CC2 pins to negotiate power:

```
    USB-C POWER NEGOTIATION
    
    Without CC resistors:  USB-C host sees no device → No power!
    With CC resistors:     USB-C host sees device → Power flows!
```

**You need 5.1K resistors, but you have 4.7K. This usually works!**

### Wiring the USB-C Breakout

```
    USB-C BREAKOUT WIRING
    
    VBUS (5V) ────┬──────────────> 5V Power Rail
                  |
    GND ─────────-┬-─────────────> GND Rail
                  |
    CC1 ────[4.7K]┴──> GND
    CC2 ────[4.7K]┴──> GND
```

**Steps:**
1. Solder or connect a wire from **VBUS** to your 5V rail
2. Connect **GND** to your ground rail
3. Connect a 4.7K resistor from **CC1** to **GND**
4. Connect a 4.7K resistor from **CC2** to **GND**
5. Plug a USB-C cable into the breakout, other end to a **phone charger** (5V 2A)

**Verify with Multimeter:**
- Touch probes to 5V rail and GND rail
- Should read ~5.0V

## TX510 Wiring Diagram

```
                TX510 to ESP32 WIRING
                
    USB-C Breakout
    +-------------+
    |    5V       |------------------------+
    |    GND      |-------------------+    |
    +-------------+                   |    |
                                      |    |
    TX510 MODULE                      |    |        ESP32
    +-------------+                   |    |    +-----------+
    |             |                   |    |    |           |
    |   VCC       |-------------------+----+----|  (not used - external power)
    |             |                   |         |           |
    |   GND       |-------------------+---------| GND       |  <-- Must connect!
    |             |                             |           |
    |   TX (pin38)|-----------------------------| GPIO4     |  (ESP32 RX)
    |             |                             |           |
    |   RX (pin39)|-----------------------------| GPIO5     |  (ESP32 TX)
    |             |                             |           |
    +-------------+                             +-----------+
    
    IMPORTANT: GND must be connected between TX510 and ESP32!
               This creates a common reference for the signals.
```

### Step-by-Step Wiring

**What You Need:**
- ESP32 (from earlier)
- TX510 Face Recognition Module (with test kit)
- USB-C Breakout Board
- 2x 4.7K resistors (for CC pins)
- 5+ Dupont wires
- USB-C cable + 5V 2A charger

**Connections:**

| TX510 Pin | → | Connection |
|---|---|---|
| VCC | → | USB-C Breakout VBUS (5V) |
| GND | → | Common GND (also to ESP32 GND) |
| TX (pin 38) | → | ESP32 GPIO4 |
| RX (pin 39) | → | ESP32 GPIO5 |

**ESP32 Connections:**
| ESP32 Pin | → | Connection |
|---|---|---|
| GND | → | Common GND (with TX510) |
| GPIO4 | → | TX510 TX |
| GPIO5 | → | TX510 RX |

> **Note:** The ESP32 is powered via USB from computer (for Serial Monitor).  
> The TX510 is powered via USB-C Breakout from charger.  
> They share a common GND.

## Test Program

1. Open the project in `firmware/tests/05_face_recognition` using VS Code.
2. Build and Upload the code to your ESP32.
3. Open Serial Monitor (115200 baud).

## Expected Results

**Physical Observations:**
- TX510 LCD screen shows boot screen, then main menu
- Infrared LEDs may be visible (faint red glow in dark)

**Serial Monitor:**
- You may see hex data when TX510 boots
- Data appears when faces are detected or buttons pressed
- If nothing appears, check wiring

## Troubleshooting

| Problem | Cause | Solution |
|---|---|---|
| TX510 screen black | No power | Check USB-C breakout, CC resistors |
| TX510 screen on, no serial data | TX/RX wired wrong | Swap GPIO4 and GPIO5 |
| TX510 screen on, no serial data | Wrong UART pins used | TX510 uses pins 38/39 (UART1) |
| ESP32 not working | GND not shared | Connect TX510 GND to ESP32 GND |
| USB-C breakout no power | Missing CC resistors | Add 4.7K or 5.1K to GND |
| Intermittent behavior | Power supply weak | Use 5V 2A (10W) minimum |

## Checkpoint: TX510 Complete

Before proceeding, verify:
- [ ] TX510 screen shows boot screen
- [ ] LCD displays main menu after boot
- [ ] Hex data appears in Serial Monitor when using module
- [ ] Module responds to face detection

---

# 12. Component Testing - LD2410 Radar

## What You'll Achieve

By the end of this section, you will:
- [ ] Wire LD2410C radar to ESP32
- [ ] Verify radar is detecting presence
- [ ] Understand radar output modes

## CRITICAL: 5V Power Required

```
+===========================================================================+
|                                                                           |
|   ⚠️ WARNING: LD2410C REQUIRES 5V POWER! ⚠️                               |
|                                                                           |
|   Connecting 3.3V will NOT work - radar will not function!               |
|                                                                           |
|   VCC must go to ESP32's VIN (5V) or external 5V supply.                 |
|                                                                           |
+===========================================================================+
```

## Wiring Diagram

```
                LD2410C to ESP32 WIRING (Watchman Node)
                
    LD2410C                               ESP32 #2
    +-----------+                     +-----------+
    |           |                     |           |
    |   VCC     |---------------------| VIN (5V)  |
    |           |                     |           |
    |   GND     |---------------------| GND       |
    |           |                     |           |
    |   TX      |---------------------| GPIO16    |  (ESP32 RX2)
    |           |                     |           |
    |   RX      |---------------------| GPIO17    |  (ESP32 TX2)
    |           |                     |           |
    +-----------+                     +-----------+
```

### Step-by-Step Wiring

**What You Need:**
- ESP32 #2 (the second one)
- LD2410C Radar Module
- 4x Female-to-Female Dupont wires

**Connections:**

| LD2410C Pin | → | ESP32 Pin | Wire Color (suggested) |
|---|---|---|---|
| VCC | → | VIN (5V) | Red |
| GND | → | GND | Black |
| TX | → | GPIO16 (RX2) | Green |
| RX | → | GPIO17 (TX2) | Yellow |

## Test Program

1. Open the project in `firmware/tests/06_radar` using VS Code.
2. Build and Upload the code to your ESP32.
3. Open Serial Monitor (115200 baud).

## Expected Output

**When Room is Empty:**
```
No presence detected
No presence detected
No presence detected
```

**When You Walk Nearby:**
```
PRESENCE DETECTED | Moving: 150cm (85%)
PRESENCE DETECTED | Moving: 120cm (92%)
PRESENCE DETECTED | Stationary: 100cm (75%)
```

**When You Stand Still:**
```
PRESENCE DETECTED | Stationary: 95cm (80%)
PRESENCE DETECTED | Stationary: 95cm (78%)
```

## Troubleshooting

| Problem | Cause | Solution |
|---|---|---|
| "LD2410C not found" | Wrong voltage | Must be 5V (not 3.3V) |
| "LD2410C not found" | TX/RX swapped | Swap GPIO16 and GPIO17 |
| "LD2410C not found" | Wrong baud rate | Must be 256000 |
| Always shows presence | Sensor aimed at wall | Point away from close objects |
| Never detects | Range too far | Move closer (under 5m) |
| Erratic readings | Electrical interference | Move away from motors/power supplies |

## Checkpoint: Radar Complete

Before proceeding, verify:
- [ ] Firmware version is displayed
- [ ] "PRESENCE DETECTED" appears when you walk nearby
- [ ] Distance readings make sense
- [ ] "No presence" appears when room is empty

---

# 13. Integration Testing - Gatekeeper Node

## What You're Building

Now we combine all **Node A** components into one working system:

```
    GATEKEEPER NODE (Node A)
    
    +--------------------------------------------------+
    |                                                  |
    |   ESP32 #1                                       |
    |     +                                            |
    |     +--- PN532 NFC (I2C)                         |
    |     +--- Finger Vein (UART2)                     |
    |     +--- TX510 Face (UART1)                      |
    |     +--- Relay (GPIO25)                          |
    |                                                  |
    +--------------------------------------------------+
```

## Complete Wiring Diagram

```
                        GATEKEEPER COMPLETE WIRING
                        
    USB-C Breakout (5V 2A source)
         |
         +---------> TX510 VCC (5V)
         |
    -----+------------------------------------- GND Rail
         |
    ESP32 #1
    +-------------------+
    | VIN  -------------|-----> PN532 VCC
    |                   |       Relay VCC
    | 3V3  -------------|-----> Finger Vein VCC
    |                   |       Pull-up resistors
    | GND  -------------|-----> All GNDs (common)
    |                   |
    | GPIO21 (SDA) -----|-----> PN532 SDA ---[4.7K]--- 3V3
    | GPIO22 (SCL) -----|-----> PN532 SCL ---[4.7K]--- 3V3
    |                   |
    | GPIO16 (RX2) -----|-----> Finger Vein TX
    | GPIO17 (TX2) -----|-----> Finger Vein RX
    |                   |
    | GPIO4 (RX1)  -----|-----> TX510 TX (pin 38)
    | GPIO5 (TX1)  -----|-----> TX510 RX (pin 39)
    |                   |
    | GPIO25       -----|-----> Relay IN
    +-------------------+
```

## Step-by-Step Integration

### Step 1: Start Fresh

1. Disconnect all components from ESP32
2. Power off everything
3. Clear your workspace

### Step 2: Wire Components One by One

**Order matters!** Add components one at a time, testing after each:

1. **PN532 NFC** (test with NFC_Test sketch)
2. **Relay** (test with Relay_Test sketch)
3. **Finger Vein** (test with Finger_Vein_Test sketch)
4. **TX510 Face** (test with TX510_Test sketch)

### Step 3: Upload Full Gatekeeper Firmware

1. Open the project: `firmware/Gatekeeper/`
2. Build and upload
3. Open Serial Monitor (115200)

**Expected Boot Sequence:**
```
=== Gatekeeper v2.0.0 ===
[BOOT] Face module OK
[BOOT] Vein module OK
[BOOT] NFC OK
[BOOT] ESP-NOW OK
[BOOT] Room: ROOM_001
[BOOT] MAC: 24:6F:28:XX:XX:XX
[BOOT] Ready. Type HELP for commands.
```

### Step 4: Configure WiFi

In Serial Monitor, type:
```
WIFI:YourNetworkName:YourPassword
```

ESP32 will restart and connect:
```
[WIFI] Connecting to YourNetworkName...
[WIFI] Connected! IP: 192.168.1.XXX
```

### Step 5: Test NFC + Relay Flow

1. Tap an NFC card
2. Serial Monitor should show:
```
[NFC] Card: 04A32B1C7D0000
[ACCESS] Denied - Not in whitelist
```

(Denied is expected - no whitelist configured yet)

## Troubleshooting Integration

| Problem | Cause | Solution |
|---|---|---|
| NFC not found at boot | I2C conflict | Check pull-ups, wiring |
| Vein module FAIL | TX/RX conflict | Ensure GPIO16/17 not used elsewhere |
| Face module FAIL | Power issue | Ensure TX510 has external 5V |
| WiFi won't connect | Wrong credentials | Double-check SSID and password |
| Random reboots | Power draw too high | Use separate power for TX510 |

## Checkpoint: Gatekeeper Integration Complete

Before proceeding, verify:
- [ ] All four "[BOOT] ... OK" messages appear
- [ ] NFC reads cards (shows UID)
- [ ] WiFi connects successfully
- [ ] Serial commands work (type HELP)

---

# 14. Integration Testing - Watchman Node

## What You're Building

Node B combines radar and relay for occupancy-based power control:

```
    WATCHMAN NODE (Node B)
    
    +--------------------------------------------------+
    |                                                  |
    |   ESP32 #2                                       |
    |     +                                            |
    |     +--- LD2410C Radar (UART2)                   |
    |     +--- Relay (GPIO26)                          |
    |                                                  |
    +--------------------------------------------------+
```

## Complete Wiring Diagram

```
                        WATCHMAN COMPLETE WIRING
                        
    ESP32 #2
    +-------------------+
    | VIN  -------------|-----> LD2410C VCC (5V)
    |                   |       Relay VCC
    |                   |
    | GND  -------------|-----> All GNDs (common)
    |                   |
    | GPIO16 (RX2) -----|-----> LD2410C TX
    | GPIO17 (TX2) -----|-----> LD2410C RX
    |                   |
    | GPIO26       -----|-----> Relay IN
    +-------------------+
```

## Step-by-Step Integration

### Step 1: Wire Components

1. Connect LD2410C as tested earlier
2. Add Relay (same as before, but to GPIO26)

### Step 2: Upload Watchman Firmware

1. Open the project: `firmware/Watchman/`
2. Change `platformio.ini` to use the correct COM port for ESP32 #2
3. Build and upload
4. Open Serial Monitor (115200)

**Expected Boot Sequence:**
```
=== Watchman v2.0.0 ===
[BOOT] Radar OK
[BOOT] Not paired. Entering beacon mode.
[BOOT] ESP-NOW OK
[BOOT] Room: ROOM_001
[BOOT] MAC: 24:6F:28:YY:YY:YY
[BOOT] Ready. Type HELP for commands.
```

### Step 3: Verify Radar Control

Walk around the room:
- **Presence detected** → Relay should click ON
- **Leave for 15+ minutes** → Relay should click OFF

(The 15-minute timeout can be shortened for testing - modify `GRACE_PERIOD_MS` in config.h)

## Checkpoint: Watchman Integration Complete

Before proceeding, verify:
- [ ] Radar reports presence correctly
- [ ] Relay activates with presence
- [ ] "Beacon mode" message appears (not paired yet)

---

# 15. ESP-NOW Pairing

## What You're Achieving

You'll wirelessly pair Gatekeeper (Node A) and Watchman (Node B):

```
    ESP-NOW PAIRING FLOW
    
    Watchman                                    Gatekeeper
    (Node B)                                    (Node A)
    +--------+                                  +--------+
    |        |    1. Beacon (broadcast)         |        |
    |        | -------------------------------> |        |
    |        |                                  |        |
    |        |    2. Pair Request               |        |
    |        | <------------------------------- |        |
    |        |                                  |        |
    |        |    3. Pair ACK                   |        |
    |        | -------------------------------> |        |
    |        |                                  |        |
    +--------+                                  +--------+
    
    Result: Both nodes know each other's MAC address
            Communication is now encrypted
```

## Pre-Pairing Wireless Test

Before pairing the actual firmware, you can verify that both ESP32 boards can talk to each other wirelessly:

1. Open `firmware/tests/07_espnow_pairing` in VS Code.
2. Upload to **BOTH** ESP32 boards.
3. Open two Serial Monitors (one for each board).
4. Follow the instructions to switch one to SENDER mode and verify the other receives the messages.

---

## Pairing Steps

### Step 1: Ensure Same Room ID

Both nodes must have the same room ID. In Serial Monitor for each:

**On Gatekeeper:**
```
ROOM:ROOM_305
```

**On Watchman:**
```
ROOM:ROOM_305
```

### Step 2: Reset Pairing (if needed)

If previously paired, reset:
```
PAIR:RESET
```

### Step 3: Power Both Nodes

1. Power on Watchman first (it sends beacons)
2. Power on Gatekeeper (it listens for beacons)

### Step 4: Watch for Pairing

**On Watchman Serial Monitor:**
```
[ESPNOW] Beacon sent
[ESPNOW] Beacon sent
[PAIR] Paired with Gatekeeper: 24:6F:28:XX:XX:XX
```

**On Gatekeeper Serial Monitor:**
```
[ESPNOW] Beacon from Watchman: 24:6F:28:YY:YY:YY
[ESPNOW] Pairing confirmed!
```

### Step 5: Verify Pairing Status

On either node:
```
PAIR:STATUS
```

Output:
```
[STATUS] Paired: YES, Room: ROOM_305, Peer: 24:6F:28:XX:XX:XX
```

## Testing ESP-NOW Communication

### Test Wake Signal

When you tap an NFC card on Gatekeeper:

**Gatekeeper:**
```
[ACCESS] GRANTED: STU_001 via NFC+BIO
[ESPNOW] Wake sent
```

**Watchman:**
```
[ESPNOW] Wake signal received
[POWER] Room power: ON
```

## Troubleshooting Pairing

| Problem | Cause | Solution |
|---|---|---|
| No beacons seen | Different room IDs | Set same room ID on both |
| Pairing fails | Out of range | Move nodes closer together |
| Intermittent connection | WiFi interference | Try different WiFi channel |
| "Protocol version mismatch" | Firmware mismatch | Upload same firmware version |

## Checkpoint: ESP-NOW Complete

Before proceeding, verify:
- [ ] Both nodes show "Paired: YES"
- [ ] Wake signal reaches Watchman
- [ ] Heartbeat messages work (check every minute)

---

# 16. Soldering Tutorial

## When to Solder

**Only solder after ALL breadboard tests pass!**

Soldering creates **permanent connections**. If you solder a mistake, you'll need to desolder (difficult) or start over.

## Soldering Safety

```
+===========================================================================+
|                         SOLDERING SAFETY                                   |
+===========================================================================+
|                                                                           |
|   1. NEVER touch the soldering iron tip (400°C = instant burn)            |
|                                                                           |
|   2. Work in VENTILATED area (solder fumes are toxic)                     |
|                                                                           |
|   3. Wear SAFETY GLASSES (solder can splatter)                            |
|                                                                           |
|   4. Use a STAND for the iron (never lay it down)                         |
|                                                                           |
|   5. UNPLUG when not in use                                               |
|                                                                           |
|   6. Keep FLAMMABLES away (paper, plastic)                                |
|                                                                           |
|   7. WASH HANDS after (solder contains lead in some types)                |
|                                                                           |
+===========================================================================+
```

## Your Soldering Iron (80W)

```
                    SOLDERING IRON ANATOMY
                    
                                         TIP (HOT!)
                                         400°C
    HANDLE                SHAFT           |
    +=====================================+=====>
    |                                     |
    | [TEMP DIAL: 250-480°C]              |
    |                                     |
    +=====================================+
    
    Settings for your work:
    - Thin wires: 320°C
    - Dupont headers: 350°C  
    - Thick wires: 380°C
```

## Basic Soldering Technique

### The 4-Step Process

```
    PERFECT SOLDER JOINT
    
    Step 1: HEAT the joint (not the solder)
    
          Iron tip
             |
             v
    =========+=========   <-- Wire
    =========|=========   <-- Pad
             |
          Contact!
          
    Step 2: APPLY solder to the HEATED joint
    
    Solder -->  [~~~]
                  \
          Iron     \
             |      \
             v       v
    =========+=========   <-- Wire
    =========|=========   <-- Pad
             |
    
    Step 3: Let solder FLOW
    
    =========+=========
    =======(●)========   <-- Solder flows and wets the joint
             |
             
    Step 4: REMOVE iron
    
    =========+=========
    =======(●)========   <-- Clean, shiny cone shape
```

### Good vs Bad Joints

```
    GOOD JOINT                    BAD JOINTS
    ==========                    ==========
    
       ___                           ___
      /   \                         (   )     <-- Cold joint (ball)
     /     \     <-- Shiny,         -----        Not enough heat
    =========        concave        
    =========                       ===o===   <-- Insufficient solder
                                               No wetting
    
                                    ======
                                    ==●===    <-- Too much solder
                                    ======       Risk of bridging
```

### Practice First!

Before touching your components, practice on:
1. Scrap wire pieces
2. Old broken electronics
3. The protoboard scraps

## Soldering Dupont Headers

For connections that need to be removable, solder female headers:

```
    HEADER TO PROTOBOARD
    
    1. Insert header into protoboard
    
       [=====]   <-- Female header
       |||||||
       O O O O   <-- Protoboard holes
       
    2. Flip board over
    
       O O O O   <-- Protoboard (component side up)
       |||||||
       [=====]   
       
    3. Solder each pin from underneath
    
       Solder here (back of board)
            v
       =====●=====
            |
          [===]
```

## Desoldering (Fixing Mistakes)

If you make a mistake:

1. **Solder Wick Method:**
   - Place copper braid on the joint
   - Heat with iron
   - Braid absorbs solder
   - Remove braid and iron together

2. **Solder Pump Method:**
   - Heat the joint
   - Place pump nozzle close
   - Press pump button (sucks up solder)

---

# 17. Permanent Assembly

## Planning Your Layout

Before soldering, plan the protoboard layout:

```
    GATEKEEPER PROTOBOARD LAYOUT (7x9cm)
    
    +--------------------------------------------------+
    |                                                  |
    |  [ESP32 MODULE - using female headers]           |
    |  ==========================================      |
    |                                                  |
    |  [4.7K] [4.7K]    <-- Pull-up resistors          |
    |     |      |                                     |
    |  Power Rails                                     |
    |  +5V ========================================    |
    |  +3.3V ======================================    |
    |  GND ========================================    |
    |                                                  |
    |  PN532      Finger     Relay    USB-C            |
    |  Header     Vein       Header   Breakout         |
    |  [====]     [====]     [===]    [====]           |
    |                                                  |
    +--------------------------------------------------+
```

## Assembly Order

1. **Solder power rails first** (5V, 3.3V, GND traces)
2. **Add female headers** for ESP32 (allows removal)
3. **Add component headers** (allows replacement)
4. **Add resistors and small parts**
5. **Test fit everything**
6. **Make connections with wire**

## Wire Management

```
    WIRE MANAGEMENT TIPS
    
    1. Cut wires to LENGTH (not too long)
    
       Bad:  ~~~~~~~~~~~~~~~~~~~~~~~~
       Good: ========
       
    2. Use COLORS consistently
    
       Red = 5V
       Orange = 3.3V
       Black = GND
       Blue = SDA/Data
       Green = SCL/Clock
       Yellow = TX
       White = RX
       
    3. BUNDLE related wires
    
       Use heat shrink tubing to group wires
       
    4. LABEL connections
    
       Use tape flags or marker on heat shrink
```

---

# 18. Enclosure & Mounting

## Waterproof Box (IP65)

Your 158x90x60mm enclosure provides:
- **IP65 rating**: Dust-tight, water-resistant
- **Clear lid**: Visible status LEDs
- **Cable glands**: Weatherproof cable entry

## Drilling for Cable Glands

```
    ENCLOSURE LAYOUT
    
    +--------------------------------------------------+
    |                                                  |
    |   [PROTOBOARD WITH ELECTRONICS]                  |
    |                                                  |
    |   [ESP32]  [PN532]  [RELAY]                      |
    |                                                  |
    +---+---+---+---+---+---+---+---+---+---+---+------+
        ^   ^   ^   ^
        |   |   |   |
       Cable Glands (PG7)
       
    Bottom of enclosure (drill holes here):
    - Power cable
    - Door lock wires
    - NFC antenna (if external)
    - Sensor wires
```

## Mounting Location

**Gatekeeper (Node A):**
- Mount beside door frame at chest height
- NFC reader should be accessible
- Finger slot visible and reachable
- Protected from rain (use overhang if outdoors)

**Watchman (Node B):**
- Mount on ceiling facing into room
- Radar has ~120° detection angle
- Avoid aiming at AC vents (false triggers)

---

# 19. Troubleshooting Encyclopedia

## Power Problems

| Symptom | Likely Cause | Solution |
|---|---|---|
| ESP32 won't power on | Bad USB cable | Try different cable |
| ESP32 keeps rebooting | Insufficient current | Use 2A power supply |
| Components work individually but not together | Power overload | Add external power for TX510 |
| Voltage reads low (4.2V instead of 5V) | Cheap power supply | Use quality 5V 2A adapter |
| ESP32 hot to touch | Short circuit | Check for solder bridges |

## Communication Problems

| Symptom | Likely Cause | Solution |
|---|---|---|
| "Module not found" | TX/RX swapped | Swap the two wires |
| Intermittent communication | Loose wire | Reseat connections |
| Works on breadboard, not when soldered | Cold solder joint | Reheat joint, add flux |
| Garbage characters in serial | Wrong baud rate | Check baud rate setting |
| I2C device not detected | Missing pull-ups | Add 4.7K resistors |

## NFC Specific

| Symptom | Likely Cause | Solution |
|---|---|---|
| "PN532 not found" | DIP switches wrong | Set: 1=OFF, 2=ON for I2C |
| Card not read | Too far away | Within 2cm of antenna |
| Only reads sometimes | Interference | Move away from metal |
| Wrong UID length | Different card type | Use NTAG215/MIFARE ISO14443A |

## Biometric Specific

| Symptom | Likely Cause | Solution |
|---|---|---|
| Finger vein no response | 5V connected | Must use 3.3V only! |
| Face module silent | No external power | Needs 5V 800mA |
| Enrollment fails | Bad positioning | Follow module prompts |
| Recognition fails | Lighting changed | Re-enroll in new lighting |

## ESP-NOW Specific

| Symptom | Likely Cause | Solution |
|---|---|---|
| Nodes won't pair | Different room IDs | Set same ROOM: on both |
| Pairing lost after reboot | Not saved to NVS | Check NVS write code |
| Intermittent connection | WiFi interference | Change WiFi channel |
| "HMAC verification failed" | Different secrets | Sync secrets from server |

---

# 20. Quick Reference Cards

## Pin Reference - Gatekeeper (Node A)

```
+===========================================================================+
|                    GATEKEEPER (NODE A) - PIN REFERENCE                     |
+===========================================================================+
|                                                                           |
|  COMPONENT         PIN          ESP32          NOTES                      |
|  -----------       ----         ------         -----                      |
|                                                                           |
|  PN532 NFC         VCC          VIN (5V)       Has 3.3V regulator         |
|                    GND          GND                                       |
|                    SDA          GPIO21         + 4.7K to 3.3V             |
|                    SCL          GPIO22         + 4.7K to 3.3V             |
|                                                                           |
|  FINGER VEIN       VCC          3V3            NOT 5V!                    |
|                    GND          GND                                       |
|                    TX           GPIO16                                    |
|                    RX           GPIO17                                    |
|                                                                           |
|  TX510 FACE        VCC          External 5V    800mA required             |
|                    GND          Common GND                                |
|                    TX(38)       GPIO4                                     |
|                    RX(39)       GPIO5                                     |
|                                                                           |
|  RELAY             VCC          VIN (5V)                                  |
|                    GND          GND                                       |
|                    IN           GPIO25                                    |
|                                                                           |
+===========================================================================+
```

## Pin Reference - Watchman (Node B)

```
+===========================================================================+
|                    WATCHMAN (NODE B) - PIN REFERENCE                       |
+===========================================================================+
|                                                                           |
|  COMPONENT         PIN          ESP32          NOTES                      |
|  -----------       ----         ------         -----                      |
|                                                                           |
|  LD2410 RADAR      VCC          VIN (5V)       NOT 3.3V!                  |
|                    GND          GND                                       |
|                    TX           GPIO16                                    |
|                    RX           GPIO17                                    |
|                                                                           |
|  RELAY             VCC          VIN (5V)                                  |
|                    GND          GND                                       |
|                    IN           GPIO26                                    |
|                                                                           |
+===========================================================================+
```

## Serial Commands Reference

```
+===========================================================================+
|                         SERIAL COMMANDS                                    |
+===========================================================================+
|                                                                           |
|  COMMAND                        DESCRIPTION                               |
|  --------                       -----------                               |
|                                                                           |
|  WIFI:ssid:password             Set WiFi credentials                      |
|  CONVEX:https://...             Set backend URL                           |
|  ROOM:ROOM_305                  Set room ID                               |
|                                                                           |
|  PAIR:STATUS                    Show pairing status                       |
|  PAIR:RESET                     Reset pairing                             |
|                                                                           |
|  ENROLL:FACE:1                  Enroll face as ID 1                       |
|  ENROLL:VEIN:1                  Enroll finger vein as ID 1                |
|                                                                           |
|  MAC                            Show MAC address                          |
|  STATUS                         Show system status                        |
|  HELP                           Show all commands                         |
|                                                                           |
+===========================================================================+
```

## Voltage Reference

```
+===========================================================================+
|                         VOLTAGE REFERENCE                                  |
+===========================================================================+
|                                                                           |
|  COMPONENT              VOLTAGE        CURRENT       NOTES                |
|  ---------              -------        -------       -----                |
|                                                                           |
|  ESP32                  5V (VIN)       500mA max                          |
|  PN532 NFC              5V             150mA         3.3V logic           |
|  Finger Vein            3.3V ONLY      100mA         3.3V logic           |
|  TX510 Face             5V             800mA         3.3V logic           |
|  LD2410 Radar           5V ONLY        100mA         3.3V logic           |
|  Relay Module           5V             70mA          3.3V trigger OK      |
|                                                                           |
+===========================================================================+
```

---

# Appendix A: Helpful Links

## Datasheets
- [ESP32 WROOM-32D Datasheet](https://www.sigmaelectronica.net/wp-content/uploads/2021/11/ESP32-WROOM-32D_pdf.pdf)
- [PN532 Wiring Guide (Adafruit)](https://learn.adafruit.com/adafruit-pn532-rfid-nfc/breakout-wiring)
- [Finger Vein Protocol PDF](https://files.waveshare.com/wiki/Finger_Vein_Scanner_Module_B/Finger_Vein_Module_Communication_Protocol_EN.pdf)
- [HLK-TX510 Info](https://blakadder.com/hlk-tx510/)
- [LD2410 Protocol](http://h.hlktech.com/download/HLK-LD2410C-24G/)

## Video Tutorials
- [Soldering for Beginners](https://www.youtube.com/watch?v=Qps9woUGkvI)
- [How to Use a Multimeter](https://www.youtube.com/watch?v=bF3OyQ3HwfU)
- [ESP32 Getting Started](https://www.youtube.com/watch?v=9b0Txt-yF7E)

## Libraries
- [Adafruit PN532](https://github.com/adafruit/Adafruit-PN532)
- [LD2410 Library](https://github.com/ncmreynolds/ld2410)

---

# Appendix B: Checklist Summary

## Pre-Assembly Checklist

- [ ] Read entire guide once before starting
- [ ] Organize all components in trays
- [ ] Set up workspace with good lighting
- [ ] Install VS Code and PlatformIO
- [ ] Test multimeter with known battery
- [ ] Touch grounded metal to discharge static

## ESP32 First Boot Checklist

- [ ] ESP32 #1 uploads blink test
- [ ] ESP32 #1 MAC address noted
- [ ] ESP32 #2 uploads blink test  
- [ ] ESP32 #2 MAC address noted

## Component Test Checklist

- [ ] PN532 NFC reads cards
- [ ] Relay clicks on command
- [ ] Finger Vein responds to commands
- [ ] TX510 shows on LCD
- [ ] LD2410 detects presence

## Integration Checklist

- [ ] Gatekeeper boots with all components OK
- [ ] Watchman boots with all components OK
- [ ] ESP-NOW pairing successful
- [ ] Wake signal reaches Watchman
- [ ] WiFi connection works

## Final Deployment Checklist

- [ ] All solder joints inspected
- [ ] Enclosure properly sealed
- [ ] Cable glands tightened
- [ ] Power supply adequate
- [ ] Mounting secure
- [ ] Serial commands tested one more time

---

**Congratulations!** If you've completed this guide, you have a working Smart Classroom access control system!

For software setup (backend, mobile app), see the main README.md.

---

*End of Assembly Guide*

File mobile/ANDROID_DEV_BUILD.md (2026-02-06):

# Android Dev Build (Expo Dev Client)

This is the simplest way to enable NFC + biometrics on Android (Expo Go cannot load native NFC modules).

## Cost
- Free to install and use on a personal Android device.
- EAS has a free tier; this uses the free workflow unless you exceed their limits.

## Prereqs
- Android phone with NFC hardware
- NFC toggled ON in Android settings
- Expo account (free) for EAS builds

## One-time setup
1) Install dev client dependency
   ```bash
   pnpm expo install expo-dev-client
   ```

2) Login + configure EAS
   ```bash
   pnpm dlx eas-cli login
   pnpm dlx eas-cli build:configure
   ```

## Build APK (cloud)
```bash
pnpm dlx eas-cli build --platform android --profile development
```

EAS will output a download link.

## Install APK on phone
- Open the link on the phone and install
- If prompted, allow "Install unknown apps" for the browser

## Run the app (dev client)
```bash
pnpm start -- --dev-client
```
Open the Dev Client app on the phone and scan the QR.

## NFC notes
- Expo Go: NFC will not work
- Dev Client: NFC works if the device supports NFC and it is enabled

## Common issues
- Phone cannot connect to Metro: ensure phone + PC are on same Wi-Fi
- Stale bundle: clear cache
  ```bash
  pnpm start -- --clear
  ```

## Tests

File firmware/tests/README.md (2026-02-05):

# Hardware Test Sketches

Standalone PlatformIO projects for testing each component individually.

## How to Use

Each test is a complete PlatformIO project. To use:

1. Copy the folder to a temporary location (or open directly)
2. Open in VS Code with PlatformIO
3. Build and upload
4. Open Serial Monitor (115200 baud)
5. Follow the on-screen instructions

## Test Order (Recommended)

1. **01_esp32_blink** - Verify ESP32 works at all
2. **02_nfc_reader** - Test PN532 NFC module
3. **03_relay** - Test relay switching
4. **04_finger_vein** - Test Waveshare finger vein sensor (3.3V ONLY!)
5. **05_face_recognition** - Test HLK-TX510 module communication
6. **06_radar** - Test LD2410C radar
7. **07_espnow_pairing** - Test ESP-NOW wireless communication between two ESP32s

## Notes

- Each test is INDEPENDENT - no dependencies on main firmware
- Tests have verbose output explaining what's happening
- Troubleshooting tips are printed on failure

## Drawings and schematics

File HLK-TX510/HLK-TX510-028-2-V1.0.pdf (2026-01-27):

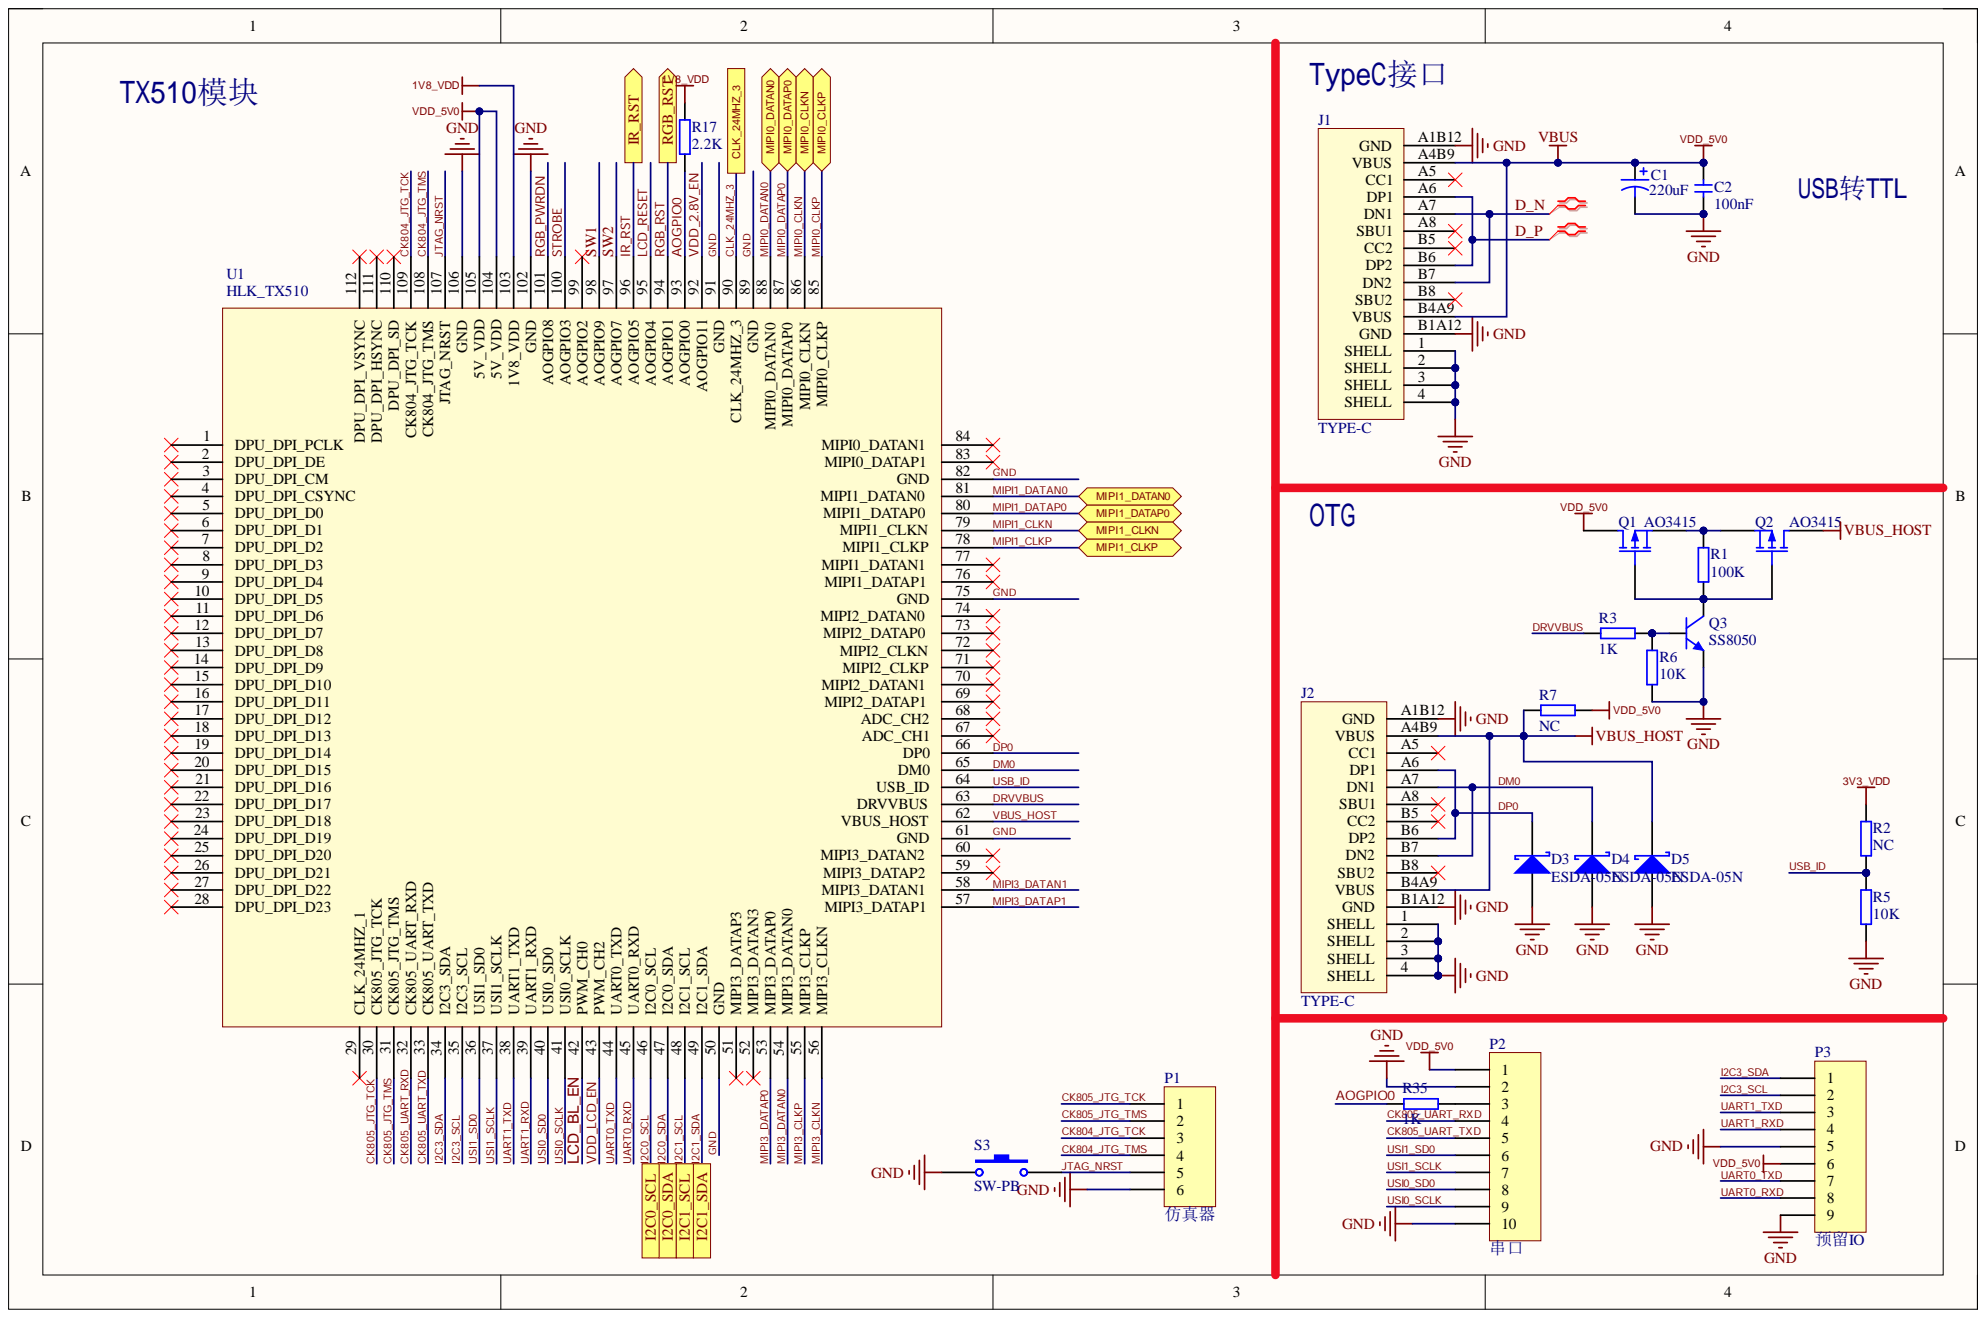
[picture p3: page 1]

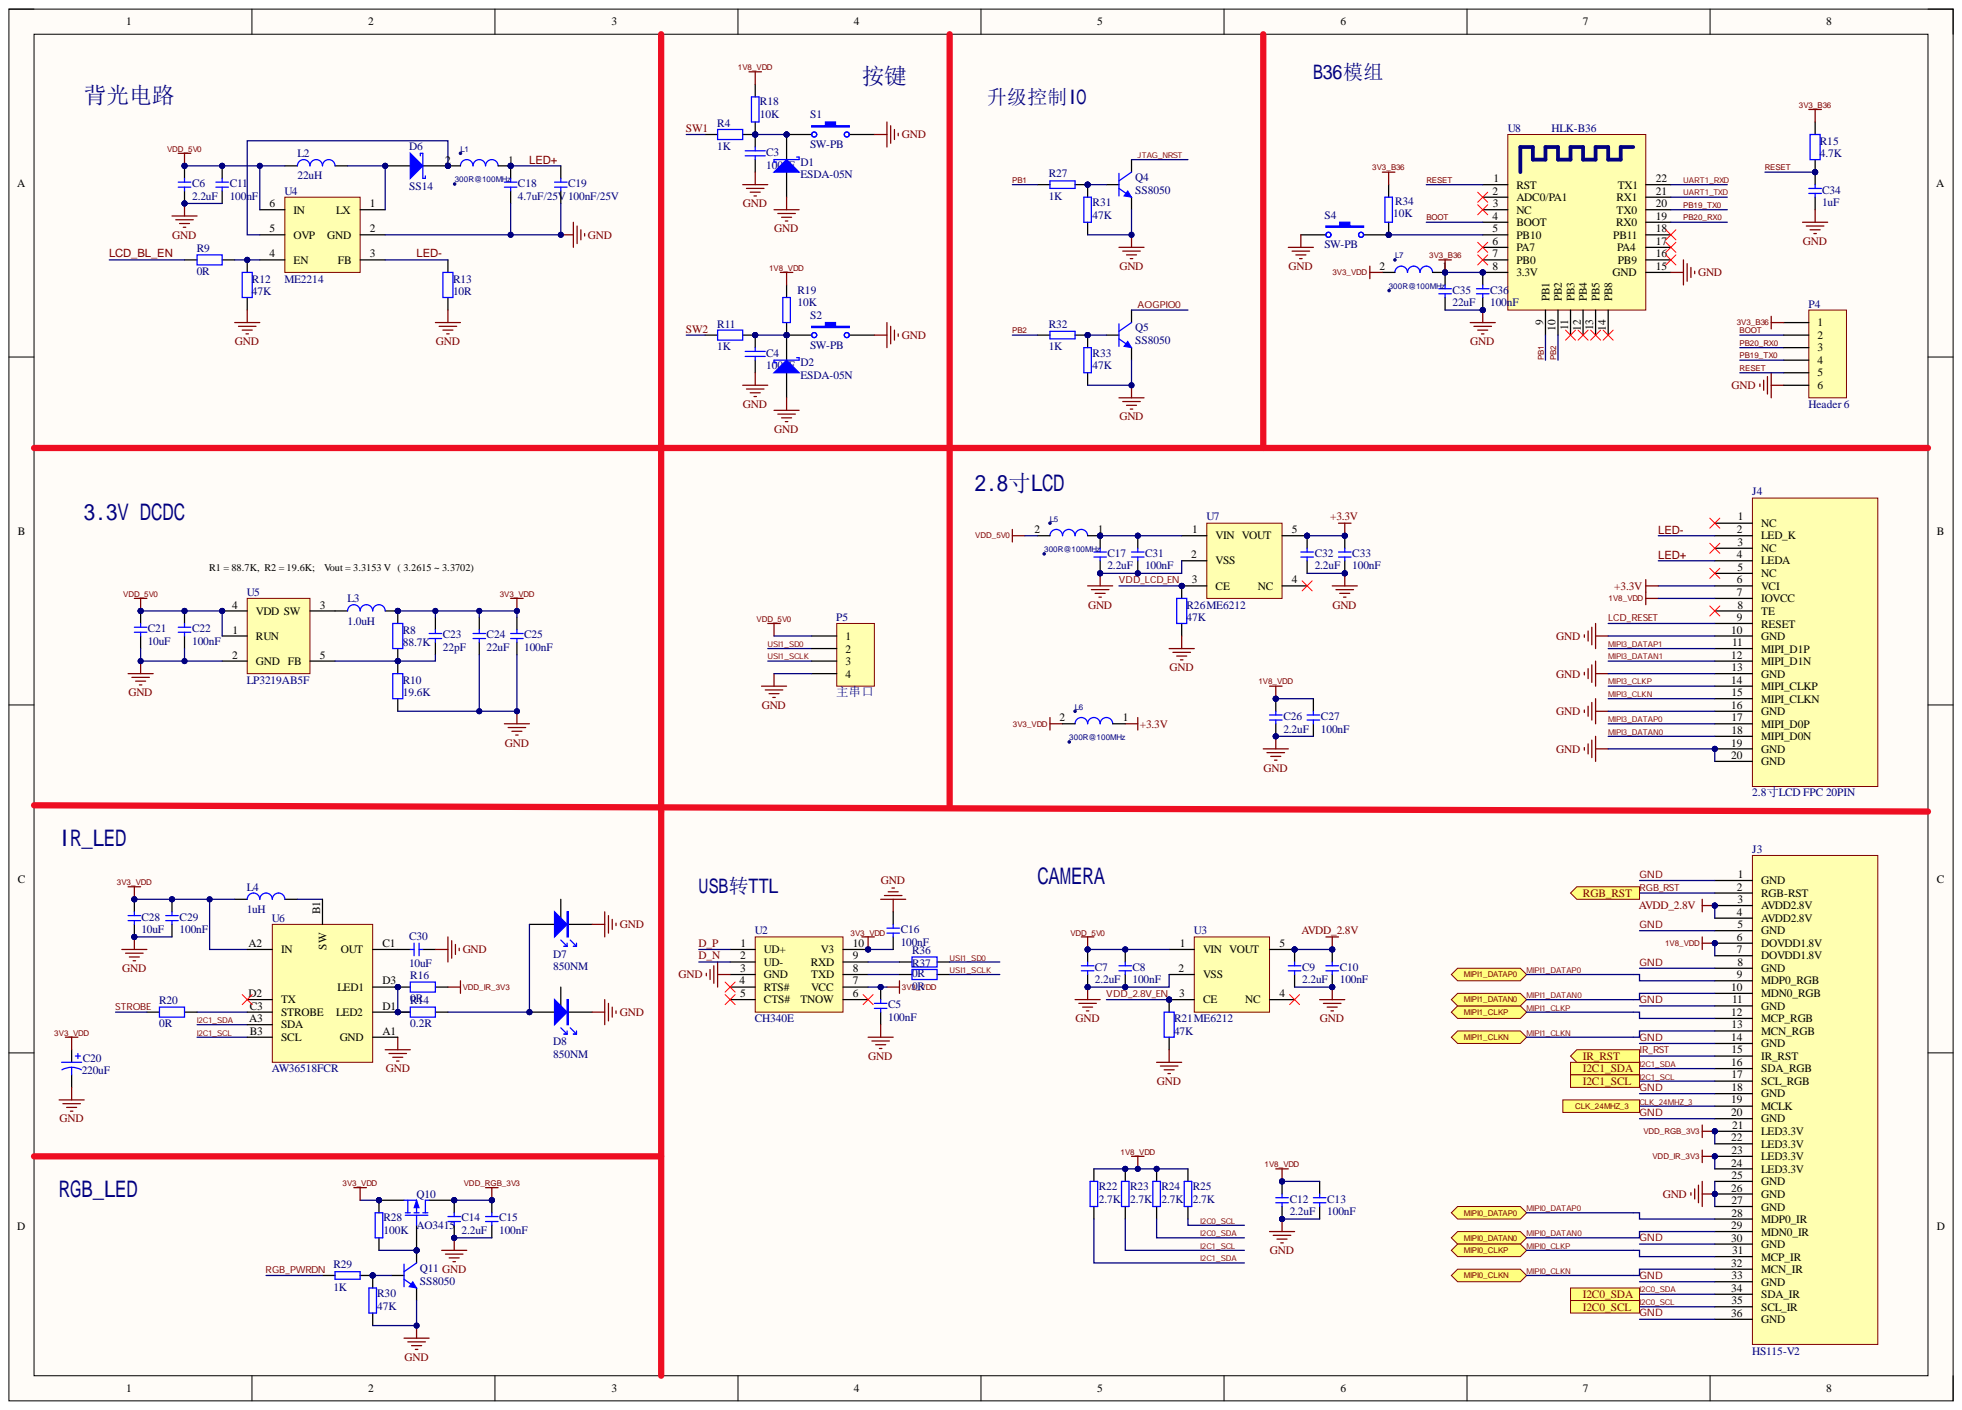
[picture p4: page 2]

RST 1 ADC0/PA1 2

C17 | C31 | VSS 2 | C32
2.2uF | 100nF

I2C1_SDA | I2C1_SDA | SDA_RGB 16
I2C1_SCL | GND 18
CLK_24MHZ_3 | MCLK 19

LED3.3V 21

I2C0_SDA | I2C0_SDA | SDA_IR 34
I2C0_SCL | GND 36

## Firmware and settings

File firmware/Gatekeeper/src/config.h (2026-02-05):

#ifndef CONFIG_H
#define CONFIG_H

#include <Arduino.h>

// =============================================================================
// FIRMWARE VERSION
// =============================================================================
#define FIRMWARE_VERSION "2.0.0"

// =============================================================================
// HARDWARE PINS
// =============================================================================
#define PN532_SDA 21
#define PN532_SCL 22
#define RELAY_PIN 25
#define STATUS_LED 2

// =============================================================================
// BIOMETRIC UART PINS
// =============================================================================
#define VEIN_RX_PIN 16
#define VEIN_TX_PIN 17
#define VEIN_BAUD 57600

#define FACE_RX_PIN 4
#define FACE_TX_PIN 5
#define FACE_BAUD 115200

// =============================================================================
// ROOM CONFIGURATION
// =============================================================================
#define DEFAULT_ROOM_ID "ROOM_001"
#define ROOM_ID_MAX_LEN 15  // Max chars (16 byte buffer - 1 for null)

// =============================================================================
// NETWORK CONFIGURATION
// Note: Credentials are stored in NVS, not hardcoded. 
// Use serial commands to configure:
//   WIFI:SSID:password
//   CONVEX:https://your-deployment.convex.site
// =============================================================================

// Default Convex URL (can be overridden via NVS)
#define DEFAULT_CONVEX_URL "https://your-deployment.convex.site"

// =============================================================================
// TIMING CONSTANTS
// =============================================================================
#define UNLOCK_DURATION_MS      5000    // Door unlock duration
#define BIOMETRIC_TIMEOUT_MS    10000   // Max time to wait for biometric
#define WHITELIST_SYNC_INTERVAL 3600000 // 1 hour
#define LOG_SYNC_INTERVAL       30000   // 30 seconds
#define HEARTBEAT_INTERVAL      60000   // 1 minute
#define CONFIG_SYNC_INTERVAL    3600000 // 1 hour - system config refresh
#define BEACON_INTERVAL_MS      2000    // ESP-NOW beacon interval
#define HEARTBEAT_TIMEOUT_MS    15000   // Consider disconnected after this
#define HTTP_TIMEOUT_MS         10000   // HTTP request timeout
#define WIFI_CONNECT_TIMEOUT_MS 30000   // WiFi connection timeout

// =============================================================================
// SECURITY CONSTANTS
// =============================================================================
#define MIN_VALID_EPOCH         1600000000  // Sept 2020 - sanity check for NTP
#define MAX_LOG_FILE_SIZE       (100 * 1024) // 100KB max log file

// ESP-NOW secrets are now fetched from Convex and stored in NVS
// Fallback values used only until first config sync completes
// These should be changed in production via the Convex dashboard
#define DEFAULT_ESP_NOW_PMK     "SmartCampusPMK01"   // 16 chars - default PMK
#define DEFAULT_ESP_NOW_SECRET  "SmartCampus24!@#"  // Default HMAC secret

// =============================================================================
// TLS CERTIFICATE
// ISRG Root X1 - Let's Encrypt Root CA (valid until 2035)
// This covers Convex and most modern HTTPS services
// =============================================================================
static const char* ROOT_CA_CERT PROGMEM = R"EOF(
-----BEGIN CERTIFICATE-----
MIIFazCCA1OgAwIBAgIRAIIQz7DSQONZRGPgu2OCiwAwDQYJKoZIhvcNAQELBQAw
TzELMAkGA1UEBhMCVVMxKTAnBgNVBAoTIEludGVybmV0IFNlY3VyaXR5IFJlc2Vh
cmNoIEdyb3VwMRUwEwYDVQQDEwxJU1JHIFJvb3QgWDEwHhcNMTUwNjA0MTEwNDM4
WhcNMzUwNjA0MTEwNDM4WjBPMQswCQYDVQQGEwJVUzEpMCcGA1UEChMgSW50ZXJu
ZXQgU2VjdXJpdHkgUmVzZWFyY2ggR3JvdXAxFTATBgNVBAMTDElTUkcgUm9vdCBY
MTCCAiIwDQYJKoZIhvcNAQEBBQADggIPADCCAgoCggIBAK3oJHP0FDfzm54rVygc
h77ct984kIxuPOZXoHj3dcKi/vVqbvYATyjb3miGbESTtrFj/RQSa78f0uoxmyF+
0TM8ukj13Xnfs7j/EvEhmkvBioZxaUpmZmyPfjxwv60pIgbz5MDmgK7iS4+3mX6U
A5/TR5d8mUgjU+g4rk8Kb4Mu0UlXjIB0ttov0DiNewNwIRt18jA8+o+u3dpjq+sW
T8KOEUt+zwvo/7V3LvSye0rgTBIlDHCNAymg4VMk7BPZ7hm/ELNKjD+Jo2FR3qyH
B5T0Y3HsLuJvW5iB4YlcNHlsdu87kGJ55tukmi8mxdAQ4Q7e2RCOFvu396j3x+UC
B5iPNgiV5+I3lg02dZ77DnKxHZu8A/lJBdiB3QW0KtZB6awBdpUKD9jf1b0SHzUv
KBds0pjBqAlkd25HN7rOrFleaJ1/ctaJxQZBKT5ZPt0m9STJEadao0xAH0ahmbWn
OlFuhjuefXKnEgV4We0+UXgVCwOPjdAvBbI+e0ocS3MFEvzG6uBQE3xDk3SzynTn
jh8BCNAw1FtxNrQHusEwMFxIt4I7mKZ9YIqioymCzLq9gwQbooMDQaHWBfEbwrbw
qHyGO0aoSCqI3Haadr8faqU9GY/rOPNk3sgrDQoo//fb4hVC1CLQJ13hef4Y53CI
rU7m2Ys6xt0nUW7/vGT1M0NPAgMBAAGjQjBAMA4GA1UdDwEB/wQEAwIBBjAPBgNV
HRMBAf8EBTADAQH/MB0GA1UdDgQWBBR5tFnme7bl5AFzgAiIyBpY9umbbjANBgkq
hkiG9w0BAQsFAAOCAgEAVR9YqbyyqFDQDLHYGmkgJykIrGF1XIpu+ILlaS/V9lZL
ubhzEFnTIZd+50xx+7LSYK05qAvqFyFWhfFQDlnrzuBZ6brJFe+GnY+EgPbk6ZGQ
3BebYhtF8GaV0nxvwuo77x/Py9auJ/GpsMiu/X1+mvoiBOv/2X/qkSsisRcOj/KK
NFtY2PwByVS5uCbMiogziUwthDyC3+6WVwW6LLv3xLfHTjuCvjHIInNzktHCgKQ5
ORAzI4JMPJ+GslWYHb4phowim57iaztXOoJwTdwJx4nLCgdNbOhdjsnvzqvHu7Ur
TkXWStAmzOVyyghqpZXjFaH3pO3JLF+l+/+sKAIuvtd7u+Nxe5AW0wdeRlN8NwdC
jNPElpzVmbUq4JUagEiuTDkHzsxHpFKVK7q4+63SM1N95R1NbdWhscdCb+ZAJzVc
oyi3B43njTOQ5yOf+1CceWxG1bQVs5ZufpsMljq4Ui0/1lvh+wjChP4kqKOJ2qxq
4RgqsahDYVvTH9w7jXbyLeiNdd8XM2w9U/t7y0Ff/9yi0GE44Za4rF2LN9d11TPA
mRGunUHBcnWEvgJBQl9nJEiU0Zsnvgc/ubhPgXRR4Xq37Z0j4r7g1SgEEzwxA57d
emyPxgcYxn/eR44/KJ4EBs+lVDR3veyJm+kXQ99b21/+jh5Xos1AnX5iItreGCc=
-----END CERTIFICATE-----
)EOF";

// =============================================================================
// DEBUG MODE
// Set to false in production to disable verbose logging
// =============================================================================
#define DEBUG_MODE true
#define TEST_MODE false

// Debug print macro
#if DEBUG_MODE
    #define DEBUG_PRINT(x) Serial.print(x)
    #define DEBUG_PRINTLN(x) Serial.println(x)
    #define DEBUG_PRINTF(...) Serial.printf(__VA_ARGS__)
#else
    #define DEBUG_PRINT(x)
    #define DEBUG_PRINTLN(x)
    #define DEBUG_PRINTF(...)
#endif

#endif // CONFIG_H

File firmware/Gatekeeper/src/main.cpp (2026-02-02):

// =============================================================================
// GATEKEEPER FIRMWARE v2.0.0
// Smart Classroom NFC + Biometric Access Control System
//
// Security Features:
// - TLS certificate verification (no insecure mode)
// - FreeRTOS mutex for thread-safe shared state
// - HMAC-SHA256 for ESP-NOW message authentication
// - Proper input validation and bounds checking
// - NVS-based credential storage (not hardcoded)
// =============================================================================

#include <Arduino.h>
#include <WiFi.h>
#include <WiFiClientSecure.h>
#include <Wire.h>
#include <Adafruit_PN532.h>
#include <Preferences.h>
#include <HTTPClient.h>
#include <ArduinoJson.h>
#include <esp_now.h>
#include <esp_task_wdt.h>
#include <freertos/semphr.h>

#include "config.h"
#include "Storage.h"
#include "NTPSync.h"
#include "FaceAuth.h"
#include "FingerVeinAuth.h"
#include "ESPNowProtocol.h"

// =============================================================================
// GLOBAL OBJECTS
// =============================================================================
Adafruit_PN532 nfc(PN532_SDA, PN532_SCL);
Preferences prefs;
HardwareSerial FaceSerial(1);
HardwareSerial VeinSerial(2);

// Task Handles
TaskHandle_t NetworkTaskHandle = NULL;

// Thread synchronization
SemaphoreHandle_t stateMutex = NULL;

// =============================================================================
// SHARED STATE (Protected by mutex)
// =============================================================================
struct SharedState {
    bool isWifiConnected = false;
    bool isPaired = false;
    uint8_t watchmanMac[6] = {0};
    char roomId[16] = {0};
    uint32_t seqNum = 0;
    unsigned long lastHeartbeatRecv = 0;
} sharedState;

// Local state (main task only)
String hardwareToken = "";
String wifiSSID = "";
String wifiPass = "";
String convexUrl = "";
unsigned long lastWhitelistSync = 0;
unsigned long lastLogSync = 0;
unsigned long lastHeartbeat = 0;
unsigned long lastConfigSync = 0;

// Dynamic configuration from Convex (stored in NVS)
String espNowPmk = "";           // 16 chars for ESP-NOW PMK
String espNowSharedSecret = "";  // Shared secret for HMAC
bool debugModeEnabled = true;    // Can be toggled remotely
uint32_t configVersion = 0;      // For detecting config changes

// Sequence number manager for replay protection
SeqNumManager seqNumManager;

// =============================================================================
// THREAD-SAFE STATE ACCESS
// =============================================================================
bool getIsPaired() {
    bool result = false;
    if (xSemaphoreTake(stateMutex, pdMS_TO_TICKS(100))) {
        result = sharedState.isPaired;
        xSemaphoreGive(stateMutex);
    }
    return result;
}

void setIsPaired(bool value) {
    if (xSemaphoreTake(stateMutex, pdMS_TO_TICKS(100))) {
        sharedState.isPaired = value;
        xSemaphoreGive(stateMutex);
    }
}

void getWatchmanMac(uint8_t* mac) {
    if (xSemaphoreTake(stateMutex, pdMS_TO_TICKS(100))) {
        memcpy(mac, sharedState.watchmanMac, 6);
        xSemaphoreGive(stateMutex);
    }
}

void setWatchmanMac(const uint8_t* mac) {
    if (xSemaphoreTake(stateMutex, pdMS_TO_TICKS(100))) {
        memcpy(sharedState.watchmanMac, mac, 6);
        xSemaphoreGive(stateMutex);
    }
}

void getRoomId(char* buffer, size_t bufSize) {
    if (xSemaphoreTake(stateMutex, pdMS_TO_TICKS(100))) {
        strncpy(buffer, sharedState.roomId, bufSize - 1);
        buffer[bufSize - 1] = '\0';
        xSemaphoreGive(stateMutex);
    }
}

void setRoomId(const char* room) {
    if (xSemaphoreTake(stateMutex, pdMS_TO_TICKS(100))) {
        strncpy(sharedState.roomId, room, sizeof(sharedState.roomId) - 1);
        sharedState.roomId[sizeof(sharedState.roomId) - 1] = '\0';
        xSemaphoreGive(stateMutex);
    }
}

uint32_t getNextSeqNum() {
    uint32_t result = 0;
    if (xSemaphoreTake(stateMutex, pdMS_TO_TICKS(100))) {
        result = ++sharedState.seqNum;
        xSemaphoreGive(stateMutex);
    }
    return result;
}

// =============================================================================
// LED PATTERNS
// =============================================================================
void ledPattern(int onMs, int offMs, int count) {
    for (int i = 0; i < count; i++) {
        digitalWrite(STATUS_LED, HIGH);
        delay(onMs);
        digitalWrite(STATUS_LED, LOW);
        delay(offMs);
    }
}

void ledSuccess() { ledPattern(100, 100, 3); }
void ledDenied() { ledPattern(100, 100, 10); }

// =============================================================================
// ESP-NOW CALLBACKS
// =============================================================================
void OnDataRecv(const uint8_t* mac, const uint8_t* incomingData, int len) {
    if (len != sizeof(ESPNowMessage)) return;
    
    ESPNowMessage msg;
    memcpy(&msg, incomingData, sizeof(msg));
    
    // Verify protocol version
    if (msg.version != ESPNOW_PROTOCOL_VERSION) {
        DEBUG_PRINTLN("[ESPNOW] Protocol version mismatch");
        return;
    }
    
    // Get current room ID safely
    char currentRoom[16];
    getRoomId(currentRoom, sizeof(currentRoom));
    
    // Verify room ID (safe comparison)
    if (strncmp(msg.roomId, currentRoom, sizeof(msg.roomId)) != 0) {
        return;  // Not for this room
    }
    
    // Verify HMAC
    if (!msg.verifyHMAC(espNowSharedSecret.c_str())) {
        DEBUG_PRINTLN("[ESPNOW] HMAC verification failed");
        return;
    }

    // Handle beacon from Watchman (pairing discovery)
    if (msg.msgType == MSG_BEACON && !getIsPaired()) {
        DEBUG_PRINTF("[ESPNOW] Beacon from Watchman: %02X:%02X:%02X:%02X:%02X:%02X\n",
            mac[0], mac[1], mac[2], mac[3], mac[4], mac[5]);
        
        // Send Pairing Request
        ESPNowMessage req;
        req.init();
        req.setRoomId(currentRoom);
        req.msgType = MSG_PAIR_REQUEST;
        req.seqNum = getNextSeqNum();
        req.timestamp = NTPSync::getEpochTime();
        req.calculateHMAC(espNowSharedSecret.c_str());

        esp_now_peer_info_t peerInfo = {};
        memcpy(peerInfo.peer_addr, mac, 6);
        peerInfo.channel = 0;
        peerInfo.encrypt = true;
        
        // Generate LMK from room ID and shared secret for encryption
        generateLMK(currentRoom, espNowSharedSecret.c_str(), peerInfo.lmk);
        
        if (!esp_now_is_peer_exist(mac)) {
            esp_err_t result = esp_now_add_peer(&peerInfo);
            if (result != ESP_OK) {
                DEBUG_PRINTF("[ESPNOW] Failed to add peer: %d\n", result);
                return;
            }
        }
        
        esp_err_t sendResult = esp_now_send(mac, (uint8_t*)&req, sizeof(req));
        if (sendResult != ESP_OK) {
            DEBUG_PRINTF("[ESPNOW] Failed to send: %d\n", sendResult);
        }
    } 
    // Handle pairing acknowledgment
    else if (msg.msgType == MSG_PAIR_ACK && !getIsPaired()) {
        setWatchmanMac(mac);
        setIsPaired(true);
        
        // Persist pairing
        prefs.begin("nvm", false);
        prefs.putBytes("watchMac", mac, 6);
        prefs.putBool("paired", true);
        prefs.end();
        
        DEBUG_PRINTLN("[ESPNOW] Pairing confirmed!");
    }
}

// =============================================================================
// ESP-NOW SEND HELPER
// =============================================================================
bool sendToWatchman(MessageType type) {
    if (!getIsPaired()) return false;
    
    char currentRoom[16];
    getRoomId(currentRoom, sizeof(currentRoom));
    
    uint8_t mac[6];
    getWatchmanMac(mac);
    
    ESPNowMessage msg;
    msg.init();
    msg.setRoomId(currentRoom);
    msg.msgType = type;
    msg.seqNum = getNextSeqNum();
    msg.timestamp = NTPSync::getEpochTime();
    msg.calculateHMAC(espNowSharedSecret.c_str());
    
    esp_err_t result = esp_now_send(mac, (uint8_t*)&msg, sizeof(msg));
    if (result != ESP_OK) {
        DEBUG_PRINTF("[ESPNOW] Send failed: %d\n", result);
        return false;
    }
    return true;
}

// =============================================================================
// ACCESS CONTROL
// =============================================================================
void openDoor(const String& userId, const String& method) {
    DEBUG_PRINTF("[ACCESS] GRANTED: %s via %s\n", userId.c_str(), method.c_str());
    
    // Wake Watchman
    sendToWatchman(MSG_WAKE);
    
    // Unlock door
    digitalWrite(RELAY_PIN, HIGH);
    ledSuccess();
    
    // Log access
    Storage::appendLog(userId.c_str(), method.c_str(), NTPSync::getEpochTime());
    
    // Keep unlocked for configured duration
    delay(UNLOCK_DURATION_MS);
    digitalWrite(RELAY_PIN, LOW);
}

bool runBiometricCheck(uint16_t expectedBiometricId) {
    DEBUG_PRINTF("[BIOMETRIC] Starting check, expecting ID: %d\n", expectedBiometricId);
    unsigned long start = millis();
    
    if (TEST_MODE) {
        delay(2000);
        return true;
    }

    while (millis() - start < BIOMETRIC_TIMEOUT_MS) {
        esp_task_wdt_reset();
        
        // Blink LED while waiting
        digitalWrite(STATUS_LED, (millis() / 500) % 2);

        // Try Face Recognition
        int faceId = FaceAuth::verifyOnce();
        if (faceId >= 0) {
            if (faceId == expectedBiometricId) {
                DEBUG_PRINTF("[BIOMETRIC] Face match: %d\n", faceId);
                digitalWrite(STATUS_LED, LOW);
                return true;
            }
            DEBUG_PRINTF("[BIOMETRIC] Face mismatch: got %d, expected %d\n", faceId, expectedBiometricId);
        }

        // Try Finger Vein
        int veinId = FingerVeinAuth::verify();
        if (veinId >= 0) {
            if (veinId == expectedBiometricId) {
                DEBUG_PRINTF("[BIOMETRIC] Vein match: %d\n", veinId);
                digitalWrite(STATUS_LED, LOW);
                return true;
            }
            DEBUG_PRINTF("[BIOMETRIC] Vein mismatch: got %d, expected %d\n", veinId, expectedBiometricId);
        }

        yield();
    }
    
    digitalWrite(STATUS_LED, LOW);
    DEBUG_PRINTLN("[BIOMETRIC] Timeout - No match");
    return false;
}

// =============================================================================
// NETWORK FUNCTIONS WITH TLS
// =============================================================================
WiFiClientSecure* createSecureClient() {
    WiFiClientSecure* client = new WiFiClientSecure();
    client->setCACert(ROOT_CA_CERT);
    client->setTimeout(HTTP_TIMEOUT_MS / 1000);
    return client;
}

void registerDevice() {
    if (WiFi.status() != WL_CONNECTED || convexUrl.isEmpty()) return;
    
    WiFiClientSecure* client = createSecureClient();
    HTTPClient http;
    http.setTimeout(HTTP_TIMEOUT_MS);
    
    if (!http.begin(*client, convexUrl + "/api/register")) {
        DEBUG_PRINTLN("[NET] Failed to begin HTTP");
        delete client;
        return;
    }
    
    http.addHeader("Content-Type", "application/json");
    
    JsonDocument req;
    req["chipId"] = WiFi.macAddress();
    req["firmwareVersion"] = FIRMWARE_VERSION;
    
    String body;
    serializeJson(req, body);
    
    int code = http.POST(body);
    if (code == 200) {
        JsonDocument res;
        DeserializationError err = deserializeJson(res, http.getString());
        if (!err && res["token"].is<const char*>()) {
            hardwareToken = res["token"].as<String>();
            prefs.begin("auth", false);
            prefs.putString("token", hardwareToken);
            prefs.end();
            DEBUG_PRINTLN("[NET] Device registered successfully");
        }
    } else {
        DEBUG_PRINTF("[NET] Registration failed: %d\n", code);
    }
    
    http.end();
    delete client;
}

void syncLogs() {
    if (hardwareToken.isEmpty() || WiFi.status() != WL_CONNECTED) return;
    
    int count = Storage::getLogCount();
    if (count == 0) return;

    File file = LittleFS.open("/logs.bin", FILE_READ);
    if (!file) return;

    JsonDocument doc;
    doc["chipId"] = WiFi.macAddress();
    JsonArray logsArr = doc["logs"].to<JsonArray>();
    
    while (file.available()) {
        AccessLog log;
        if (file.read((uint8_t*)&log, sizeof(AccessLog)) != sizeof(AccessLog)) {
            break;
        }
        JsonObject logObj = logsArr.add<JsonObject>();
        logObj["userId"] = log.userId;
        logObj["method"] = log.method;
        logObj["action"] = "ATTENDANCE";
        logObj["result"] = "success";
        logObj["timestamp"] = log.timestamp;
        logObj["timestampType"] = NTPSync::isTimeValid() ? "ntp" : "local";
    }
    file.close();

    WiFiClientSecure* client = createSecureClient();
    HTTPClient http;
    http.setTimeout(HTTP_TIMEOUT_MS);
    
    if (!http.begin(*client, convexUrl + "/api/logs")) {
        delete client;
        return;
    }
    
    http.addHeader("Content-Type", "application/json");
    http.addHeader("Authorization", "Bearer " + hardwareToken);
    
    String body;
    serializeJson(doc, body);
    
    int httpCode = http.POST(body);
    if (httpCode == 200) {
        Storage::clearLogs();
        DEBUG_PRINTLN("[SYNC] Logs uploaded successfully");
    } else {
        DEBUG_PRINTF("[SYNC] Log upload failed: %d - %s\n", httpCode, http.getString().c_str());
    }
    
    http.end();
    delete client;
}

void syncWhitelist() {
    if (hardwareToken.isEmpty() || WiFi.status() != WL_CONNECTED) return;
    
    WiFiClientSecure* client = createSecureClient();
    HTTPClient http;
    http.setTimeout(HTTP_TIMEOUT_MS);
    
    String url = convexUrl + "/api/whitelist?chipId=" + WiFi.macAddress();
    if (!http.begin(*client, url)) {
        delete client;
        return;
    }
    
    http.addHeader("Authorization", "Bearer " + hardwareToken);
    
    int httpCode = http.GET();
    if (httpCode == 200) {
        JsonDocument res;
        DeserializationError error = deserializeJson(res, http.getString());
        if (!error) {
            JsonArray entries = res["entries"];
            if (!entries.isNull()) {
                // Store card UID -> studentId mapping
                prefs.begin("whitelist", false);
                prefs.clear();
                for (JsonObject entry : entries) {
                    const char* uid = entry["uid"];
                    const char* sid = entry["sid"];
                    if (uid && sid) {
                        prefs.putString(uid, sid);
                    }
                }
                prefs.end();
                
                // Store studentId -> biometricId mapping (separate namespace)
                prefs.begin("biometrics", false);
                prefs.clear();
                for (JsonObject entry : entries) {
                    const char* sid = entry["sid"];
                    uint16_t bioId = entry["bioId"] | 0;
                    if (sid && bioId > 0) {
                        prefs.putUShort(sid, bioId);
                    }
                }
                prefs.end();
                
                DEBUG_PRINTF("[SYNC] Whitelist updated: %d entries\n", entries.size());
            }
        }
    } else {
        DEBUG_PRINTF("[SYNC] Whitelist sync failed: %d\n", httpCode);
    }
    
    http.end();
    delete client;
}

/**
 * Fetches system configuration (ESP-NOW secrets, debug mode) from Convex.
 * Called after registration and periodically (hourly).
 */
void syncSystemConfig() {
    if (hardwareToken.isEmpty() || WiFi.status() != WL_CONNECTED) return;
    
    WiFiClientSecure* client = createSecureClient();
    HTTPClient http;
    http.setTimeout(HTTP_TIMEOUT_MS);
    
    String url = convexUrl + "/api/config?chipId=" + WiFi.macAddress();
    if (!http.begin(*client, url)) {
        delete client;
        return;
    }
    
    http.addHeader("Authorization", "Bearer " + hardwareToken);
    
    int httpCode = http.GET();
    if (httpCode == 200) {
        JsonDocument res;
        DeserializationError error = deserializeJson(res, http.getString());
        if (!error) {
            const char* pmk = res["pmk"];
            const char* secret = res["secret"];
            bool debug = res["debug"] | true;
            uint32_t version = res["version"] | 0;
            
            // Only update if version changed (or first time)
            if (version != configVersion && pmk && secret) {
                espNowPmk = String(pmk);
                espNowSharedSecret = String(secret);
                debugModeEnabled = debug;
                configVersion = version;
                
                // Persist to NVS
                prefs.begin("config", false);
                prefs.putString("pmk", espNowPmk);
                prefs.putString("secret", espNowSharedSecret);
                prefs.putBool("debug", debugModeEnabled);
                prefs.putULong("version", configVersion);
                prefs.end();
                
                DEBUG_PRINTLN("[CONFIG] System configuration updated from Convex");
                
                // Re-initialize ESP-NOW with new PMK
                // Note: This requires ESP-NOW to be restarted with new encryption keys
                // For simplicity, we just store it - full re-init would require more work
            }
        }
    } else {
        DEBUG_PRINTF("[CONFIG] Config sync failed: %d\n", httpCode);
    }
    
    http.end();
    delete client;
}
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
void loop() {
    esp_task_wdt_reset();
    handleSerial();
    
    // Continue any ongoing vein enrollment
    if (FingerVeinAuth::getEnrollStep() > 0) {
        FingerVeinAuth::Result result = FingerVeinAuth::enroll(0);
        if (result == FingerVeinAuth::SUCCESS) {
            Serial.println("[ENROLL] Vein enrollment complete!");
            ledSuccess();
        } else if (result == FingerVeinAuth::TIMEOUT || result == FingerVeinAuth::SENSOR_ERROR) {
            Serial.println("[ENROLL] Vein enrollment failed");
            ledDenied();
        }
    }
    
    // Check for face enrollment completion
    if (FaceAuth::getState() == FaceAuth::ENROLLING) {
        if (FaceAuth::isEnrollComplete()) {
            Serial.println("[ENROLL] Face enrollment complete!");
            ledSuccess();
        }
    }
    
    // NFC card reading
    uint8_t uid[7] = {0};
    uint8_t uidLength = 0;
    
    if (nfc.readPassiveTargetID(PN532_MIFARE_ISO14443A, uid, &uidLength, 100)) {
        // Convert UID to hex string
        char cardUID[15] = {0};  // 7 bytes * 2 + null
        for (uint8_t i = 0; i < uidLength && i < 7; i++) {
            sprintf(&cardUID[i * 2], "%02X", uid[i]);
        }
        
        DEBUG_PRINTF("[NFC] Card: %s\n", cardUID);
        
        // Check whitelist
        prefs.begin("whitelist", true);
        bool isInWhitelist = prefs.isKey(cardUID);
        String sid = isInWhitelist ? prefs.getString(cardUID) : "";
        prefs.end();
        
        if (isInWhitelist) {
            // Check if biometric verification required (students)
            if (sid.startsWith("STU")) {
                // Look up expected biometric ID for this student
                prefs.begin("biometrics", true);
                uint16_t expectedBioId = prefs.getUShort(sid.c_str(), 0);
                prefs.end();
                
                if (expectedBioId == 0) {
                    DEBUG_PRINTLN("[ACCESS] Student has no enrolled biometric");
                    ledDenied();
                    Serial.println("[ACCESS] Denied - No biometric enrolled");
                } else if (runBiometricCheck(expectedBioId)) {
                    openDoor(sid, "NFC+BIO");
                } else {
                    ledDenied();
                    Serial.println("[ACCESS] Denied - Biometric mismatch");
                }
            } else {
                // Staff/Admin - NFC only
                openDoor(sid, "NFC");
            }
        } else {
            Serial.println("[ACCESS] Denied - Not in whitelist");
            ledDenied();
        }
        
        delay(1000);  // Debounce
    }
}

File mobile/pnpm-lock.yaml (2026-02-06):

lockfileVersion: '9.0'

settings:
  autoInstallPeers: true
  excludeLinksFromLockfile: false

importers:

  .:
    dependencies:
      '@auth/core':
        specifier: 0.37.0
        version: 0.37.0
      '@convex-dev/auth':
        specifier: ^0.0.90
        version: 0.0.90(@auth/core@0.37.0)(convex@1.31.6(react@19.1.0))(react@19.1.0)
      '@expo-google-fonts/inter':
        specifier: ^0.4.2
        version: 0.4.2
      '@expo-google-fonts/playfair-display':
        specifier: ^0.4.2
        version: 0.4.2
      '@react-native-async-storage/async-storage':
        specifier: ^2.2.0
        version: 2.2.0(react-native@0.81.5(@babel/core@7.28.6)(@types/react@19.1.17)(react@19.1.0))
      convex:
        specifier: ^1.31.6
        version: 1.31.6(react@19.1.0)
      expo:
        specifier: ~54.0.33
        version: 54.0.33(@babel/core@7.28.6)(react-native@0.81.5(@babel/core@7.28.6)(@types/react@19.1.17)(react@19.1.0))(react@19.1.0)
      expo-dev-client:
        specifier: ~6.0.20
        version: 6.0.20(expo@54.0.33(@babel/core@7.28.6)(react-native@0.81.5(@babel/core@7.28.6)(@types/react@19.1.17)(react@19.1.0))(react@19.1.0))
      expo-font:
        specifier: ~14.0.11
        version: 14.0.11(expo@54.0.33(@babel/core@7.28.6)(react-native@0.81.5(@babel/core@7.28.6)(@types/react@19.1.17)(react@19.1.0))(react@19.1.0))(react-native@0.81.5(@babel/core@7.28.6)(@types/react@19.1.17)(react@19.1.0))(react@19.1.0)
      expo-haptics:
        specifier: ^15.0.8
        version: 15.0.8(expo@54.0.33(@babel/core@7.28.6)(react-native@0.81.5(@babel/core@7.28.6)(@types/react@19.1.17)(react@19.1.0))(react@19.1.0))
      expo-local-authentication:
        specifier: ^17.0.8
        version: 17.0.8(expo@54.0.33(@babel/core@7.28.6)(react-native@0.81.5(@babel/core@7.28.6)(@types/react@19.1.17)(react@19.1.0))(react@19.1.0))
      expo-location:
        specifier: ^19.0.8
        version: 19.0.8(expo@54.0.33(@babel/core@7.28.6)(react-native@0.81.5(@babel/core@7.28.6)(@types/react@19.1.17)(react@19.1.0))(react@19.1.0))
      expo-notifications:
        specifier: ^0.32.16
        version: 0.32.16(expo@54.0.33(@babel/core@7.28.6)(react-native@0.81.5(@babel/core@7.28.6)(@types/react@19.1.17)(react@19.1.0))(react@19.1.0))(react-native@0.81.5(@babel/core@7.28.6)(@types/react@19.1.17)(react@19.1.0))(react@19.1.0)
      expo-secure-store:
        specifier: ^15.0.8
        version: 15.0.8(expo@54.0.33(@babel/core@7.28.6)(react-native@0.81.5(@babel/core@7.28.6)(@types/react@19.1.17)(react@19.1.0))(react@19.1.0))
      expo-splash-screen:
        specifier: ~31.0.13
        version: 31.0.13(expo@54.0.33(@babel/core@7.28.6)(react-native@0.81.5(@babel/core@7.28.6)(@types/react@19.1.17)(react@19.1.0))(react@19.1.0))
      expo-status-bar:
        specifier: ~3.0.9
        version: 3.0.9(react-native@0.81.5(@babel/core@7.28.6)(@types/react@19.1.17)(react@19.1.0))(react@19.1.0)
      lucide-react-native:
        specifier: ^0.473.0
        version: 0.473.0(react-native-svg@15.12.1(react-native@0.81.5(@babel/core@7.28.6)(@types/react@19.1.17)(react@19.1.0))(react@19.1.0))(react-native@0.81.5(@babel/core@7.28.6)(@types/react@19.1.17)(react@19.1.0))(react@19.1.0)
      react:
        specifier: ^19.1.0
        version: 19.1.0
      react-dom:
        specifier: ^19.1.0
        version: 19.1.0(react@19.1.0)
      react-native:
        specifier: ^0.81.5
        version: 0.81.5(@babel/core@7.28.6)(@types/react@19.1.17)(react@19.1.0)
      react-native-nfc-manager:
        specifier: ^3.17.2
        version: 3.17.2(@expo/config-plugins@54.0.4)
      react-native-safe-area-context:
        specifier: ^5.1.0
        version: 5.6.2(react-native@0.81.5(@babel/core@7.28.6)(@types/react@19.1.17)(react@19.1.0))(react@19.1.0)
      react-native-svg:
        specifier: ^15.12.1
        version: 15.12.1(react-native@0.81.5(@babel/core@7.28.6)(@types/react@19.1.17)(react@19.1.0))(react@19.1.0)
      react-native-web:
        specifier: ^0.21.2
        version: 0.21.2(react-dom@19.1.0(react@19.1.0))(react@19.1.0)
    devDependencies:
      '@types/react':
        specifier: ~19.1.10
        version: 19.1.17
      typescript:
        specifier: ~5.9.2
        version: 5.9.3
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

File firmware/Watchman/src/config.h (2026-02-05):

#ifndef CONFIG_H
#define CONFIG_H

#include <Arduino.h>

// =============================================================================
// FIRMWARE VERSION
// =============================================================================
#define FIRMWARE_VERSION "2.0.0"

// =============================================================================
// HARDWARE PINS
// =============================================================================
#define RADAR_RX 16
#define RADAR_TX 17
#define RADAR_BAUD 256000

#define RELAY_PIN 26
#define STATUS_LED 2

// =============================================================================
// ROOM CONFIGURATION
// =============================================================================
#define DEFAULT_ROOM_ID "ROOM_001"
#define ROOM_ID_MAX_LEN 15

// =============================================================================
// TIMING CONSTANTS
// =============================================================================
#define GRACE_PERIOD_MS     300000  // 5 minutes
#define STANDBY_DELAY_MS    60000   // 1 minute additional before cutting power
#define BEACON_INTERVAL_MS  2000    // ESP-NOW beacon interval when not paired
#define HEARTBEAT_TIMEOUT_MS 15000  // Consider disconnected after this
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

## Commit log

2026-01-22 docs: add attendance flow with biometric + access control model
2026-01-22 docs: add offline mode with flowcharts + timestamp handling
2026-01-22 docs: rewrite with clean Mermaid flowcharts
2026-01-22 docs: add device binding anti-sharing check
2026-01-23 docs: add 1:1 card binding + deviceId in schema
2026-01-23 docs: add system management (device reg, WiFi, OTA, monitoring, recovery)
2026-01-23 docs: comprehensive system blueprint updates
    - Add teacher scan IN/OUT requirements vs student scan IN only
    - Clarify biometrics are on-device auth (true/false only, not collected)
    - Add user status field for archiving (enrolled/graduated/expelled)
    - Add scan order memory calculations (NVS storage details)
    - Add cost projections (~100 students = /month)
    - Add admin/teacher notification triggers
    - Add accessibility features (haptic, VoiceOver, large touch targets)
    - Add localization (English + Khmer)
    - Add magnetic lock fail-safe documentation
    - Add edge cases (substitute teacher, manual override, data migration)
    - Add demo mode reminder for App Store
    - Add in-app issue reporting with expandi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
2026-01-23 feat(mobile): add React Native Expo mobile app with role-based dashboards
    - Login screen with demo role switching (student/teacher/admin)
    - Student dashboard with gate access and attendance features
    - Teacher dashboard with scan in/out and class management
    - Admin dashboard with device monitoring and alerts
    - Profile screen with NFC card linking flow
    - Reusable components (Button, Input, Typography)
    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
2026-01-24 docs: add hardware inventory tracker for ESP32 NFC system
2026-01-24 Update inventory with verified specs and actual cart contents
    - Update cart to match actual order (5.51 total)
    - Add soldering iron (80W, 220V EU plug)
    - Change Dupont wires from 10cm to 30cm
    - Fix PN532 I2C address: 0x24 → 0x48 (verified from Adafruit docs)
    - Mark GPIO 5 as strapping pin (verified from Espressif docs)
    - Add notes section explaining strapping pin behavior and I2C pull-ups
2026-01-26 Integrate Convex Auth and refactor to modular architecture
    - Implemented secure backend authentication with Convex Auth.
    - Refactored app structure to use Context API and custom hooks.
    - Added global data synchronization for instant tab switching.
    - Implemented admin features for user creation and deletion.
    - Added cross-platform secure storage (Web/Mobile) support.
    - Optimized performance by eliminating redundant database queries.
2026-01-26 feat: migrate from mock data to live Convex backend
    - Expanded Convex schema with classes, sessions, and staff tasks.
    - Implemented real authentication seeding and login credential injection.
    - Refactored all dashboards (Admin, Teacher, Student, Staff) to use live data.
    - Removed all hardcoded mock data files and unused demo logic.
    - Implemented an 'Absolute Gate' authentication flow with elegant crossfade.
    - Standardized navigation and improved type safety across the mobile app.
2026-01-27 security: harden backend auth and hardware device management
2026-01-27 docs: align HLK-TX510 specs with manufacturer data and add hardware docs
    [1-TX510_KIT.SchDoc, 2-LCD&CAMERA.SchDoc, HLK-TX510-028-2-V1.0.PRJPCB]
2026-01-27 docs: fix hardware wiring conflicts and align TX510 specs with manufacturer data
2026-01-27 feat: standardize UI layout, typography, and responsiveness across the app
    - Standardized all screens to 34px padding and high-end editorial typography.
    - Improved header consistency with pixel-perfect vertical alignment (44px height).
    - Enhanced responsiveness for room grids and scrollable filters on mobile.
    - Resolved 'double-fade' transition issues and optimized navigation feel.
    - Cleaned up technical debt, unused imports, and hook order violations.
2026-01-28 feat: implement high-fidelity campus simulation with functional dashboards
    - Overhauled Convex seed with a 7-day history of 150+ realistic logs and 25+ users.
    - Updated schema to support room types, student majors, and academic years.
    - Refactored Student Dashboard and Classes screen to use live reactive queries.
    - Implemented real mutations for staff cleaning tasks and admin room management.
    - Added live 'Remote Control' for rooms including lock cycling and power toggles.
    - Fixed ArgumentValidationError in user detail view and removed redundant local states.
    - Cleaned up technical debt and ensured pixel-perfect data-to-UI sync.
2026-01-29 feat: implement real hardware integration and esp32 firmware
    - Replaced mobile NFC/Biometric/GPS mocks with real sensor logic and haptics.
    - Built dual-node ESP32 firmware (Gatekeeper/Watchman) with auto-provisioning.
    - Implemented local NVS whitelist and LittleFS logging for offline access.
    - Hardened backend sync with token-based hardware authentication.
    [config.h, main.cpp]
2026-01-29 feat: implement homeroom-based attendance system with automated session management
    - Implemented automated session generation via crons and lib/timezone utilities
    - Added homeroom, calendar, and schedule management modules
    - Updated schema with device health monitoring and security indexes
    - Refactored Staff and Teacher dashboards for homeroom visibility
    - Standardized timezone handling for Cambodia (UTC+7)
    - Fixed type safety for room queries in the mobile app
    - Integrated ESP32 Gatekeeper firmware support for biometric auth
    [FaceAuth.h, FingerVeinAuth.h]
2026-01-30 feat: implement rock-solid system hardening and high-fidelity campus simulation
    - Implemented server-side GPS geofencing and clock-drift protection for attendance.
    - Overhauled firmware sync logic to ensure atomic, fail-safe log uploads.
    - Restored high-fidelity simulation with 50+ users, 14 rooms, and live demo sessions.
    - Fixed teacher dashboard empty states and mapped quick access to power-user accounts.
    - Achieved zero-error type safety across mobile and backend projects.
    [main.cpp]
2026-02-02 chore: improve app config, seed data, and fix UI precision
    - Configure app.json with proper bundle IDs and disable new architecture for NFC stability
    - Remove duplicate package-lock.json (pnpm only)
    - Make seed dynamic (uses current day, generates 5-day teacher history)
    - Fix teaching hours widget to show 1 decimal place
    [pnpm-lock.yaml]
2026-02-02 security: comprehensive hardening for firmware and backend
    Firmware:
    - Add TLS certificate verification (ISRG Root X1)
    - Replace XOR checksum with HMAC-SHA256 for ESP-NOW
    - Add FreeRTOS mutex for thread-safe shared state
    - Add buffer bounds checking in FaceAuth and FingerVeinAuth
    - Add NVS-based credential storage (no hardcoded secrets)
    - Add log rotation and proper epoch validation
    Backend:
    - Add auth checks to sessions, schedule, staffTasks queries
    - Add role-based access control (students see only their data)
    - Add constant-time token comparison
    - Remove debug console.log statements
    - Guard demo credentials behind __DEV__ flag
    All builds verified passing.
    [FaceAuth.h, FingerVeinAuth.h, config.h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]
2026-02-02 security: centralized secrets management and auth hardening
    - Add systemConfig table for ESP-NOW secrets managed via Convex dashboard
    - Add /api/config endpoint for devices to fetch secrets dynamically
    - Add auth checks to getSessionsByDate, getTeacherStats, getCurrentTeacherSession
    - Fix antiCheat data spreading vulnerability in attendance.ts
    - Fix time drift check bypass (now validates regardless of timeSource)
    - Fix error message leakage in /api/register endpoint
    - Add production safety guard to seed (blocks if debugMode=false)
    - Remove hardcoded ESP_NOW_PMK and ESP_NOW_SHARED_SECRET from config.h
    - Gatekeeper fetches secrets from Convex on boot and hourly refresh
    - En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
    [config.h, main.cpp]
2026-02-02 fix: biometric ID verification + hardware testing checklist
    - Add biometricId field to users schema
    - Include bioId in whitelist response for firmware
    - Store studentId -> biometricId mapping in NVS during whitelist sync
    - Fix runBiometricCheck() to compare returned ID with expected ID
    - Look up expected biometricId from NVS before verification
    - Add comprehensive hardware testing checklist (HARDWARE_TESTING.md)
    Security: Closes biometric mismatch vulnerability where any enrolled
    face/finger could unlock door for any whitelisted card holder.
    [main.cpp]
2026-02-04 docs: comprehensive hardware assembly guide and standalone test sketches
    - Add ASSEMBLY_GUIDE.md (~2100 lines) - complete beginner-friendly guide covering:
    - Safety, ESD protection, and workspace setup
    - Tool explanations (multimeter, soldering iron, breadboard)
    - Step-by-step component testing with ASCII wiring diagrams
    - ESP-NOW pairing between Gatekeeper and Watchman nodes
    - Soldering tutorial for first-timers
    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
2026-02-04 chore: remove redundant HARDWARE_TESTING.md (superseded by ASSEMBLY_GUIDE.md)
2026-02-04 docs: add note about PN532 I2C pull-up resistor values
    Adafruit recommends 1.5K for PN532, but user has 4.7K.
    Added note explaining:
    - Try 4.7K first (often works)
    - Use parallel resistors if issues occur (~2.35K)
2026-02-04 docs: fix PN532 pull-up guidance to be honest about uncertainty
    Previous note incorrectly cited Adafruit specs for a different board.
    User's AliExpress PN532 V3 may have built-in pull-ups.
    Now recommends: try without first, add only if needed.
2026-02-05 refactor: consolidate test code, remove duplication from ASSEMBLY_GUIDE
    - Remove ~550 lines of embedded code from ASSEMBLY_GUIDE.md
    - Point users to firmware/tests/ instead of duplicating code
    - Add new 05_face_recognition test for HLK-TX510 module
    - Rename 05_radar -> 06_radar, 06_espnow_pair -> 07_espnow_pairing
    - Fix ld2410 library version (use latest instead of non-existent 1.0.7)
    - Update firmware/tests/README.md with correct test order
    - All 7 test sketches verified to compile successfully
    [main.cpp]
2026-02-05 fix: biometric tests use production drivers with LED_BUILTIN fallback
    - 04_finger_vein: uses FingerVeinAuth.h from Gatekeeper, interactive menu
    - 05_face_recognition: uses FaceAuth.h from Gatekeeper, interactive menu
    - Added C++17 build flags for inline static variables
    - Added LED_BUILTIN fallback for ESP32 (pin 2)
    - Both tests now build successfully
    [main.cpp]
2026-02-05 refactor: standalone biometric tests with minimal protocol
    Tests are now self-contained hardware verification sketches:
    - No dependencies on production Gatekeeper code
    - Minimal protocol implementation (just WHO_AM_I checks)
    - Easy to copy, share, and modify
    - Clear troubleshooting output for wiring issues
    04_finger_vein: Sends ReadSysPara/GetTemplateCount (0xEF01 protocol)
    05_face_recognition: Sends QueryModuleInfo/GetFaceCount (0xEFAA protocol)
    [main.cpp]
2026-02-05 feat: full incoming inspection tests for biometric sensors
    Tests now verify complete sensor functionality, not just communication:
    04_finger_vein:
    1. Check alive (ReadSysPara)
    2. Get template count (storage works)
    3. Capture image (optics/IR LED work)
    4. Enroll finger (capture + extract + store)
    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
